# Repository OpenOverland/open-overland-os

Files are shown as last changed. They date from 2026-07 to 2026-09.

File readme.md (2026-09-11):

# ESP32-based control board

Custom designed control board build around ESP32-S3 module.

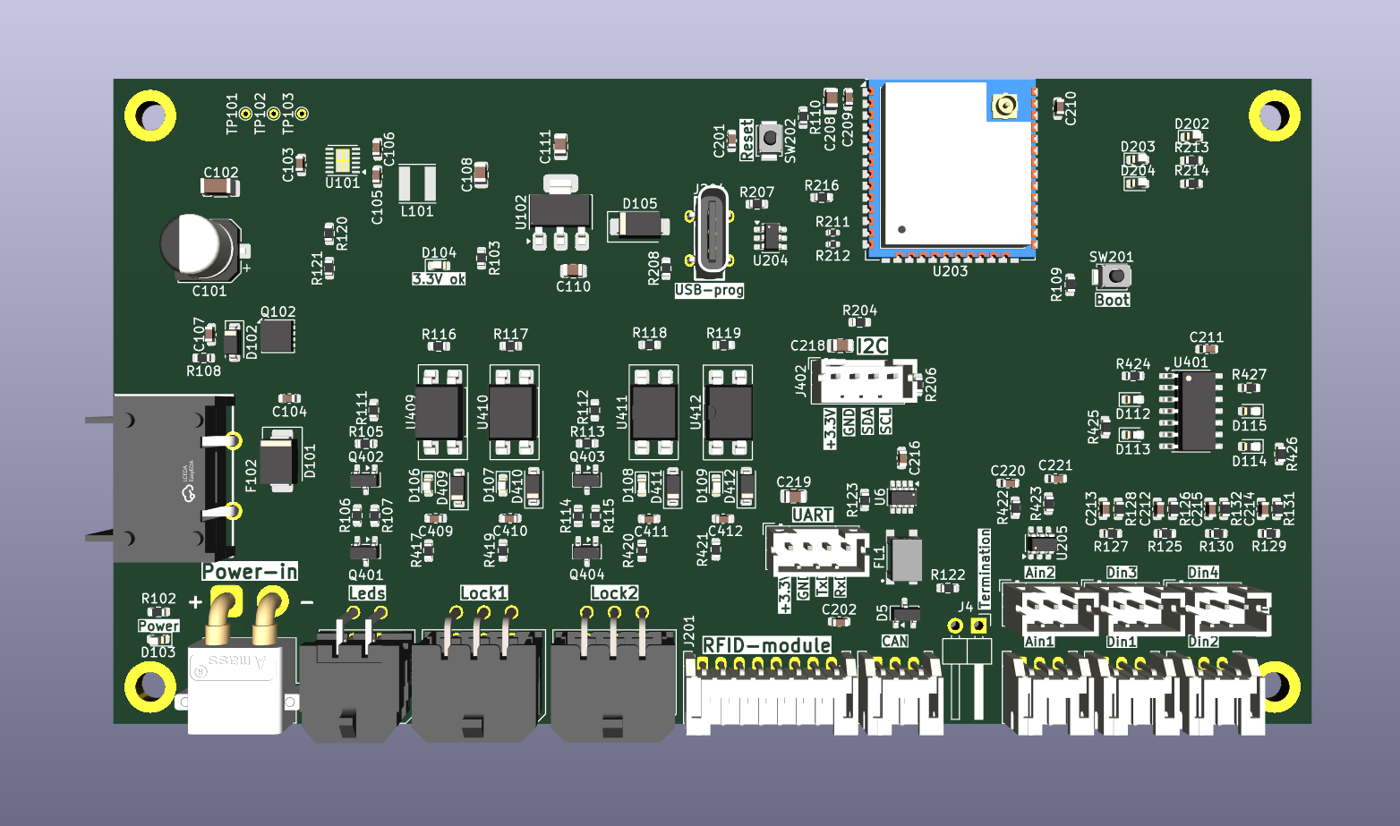
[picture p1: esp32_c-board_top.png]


### Specification:

1. Board dimensions: 130 x 70 mm, 4x M3-mounting holes (3.2mm inner diameter);
2. XT30 header as main Power-input (up to 15 Amps);
3. Blade-fuse holder on the board (in light-green color);
4. Designed around ESP32-S3-WROOM-1U module (external antenna needs to be attached to its I-PEX/u.FL connector);
5. 2x 6-pin Molex MicroFit 3.0 headers for a connection with the Locks;
6. 1x 4-pin Molex MicroFit 3.0 header for a connection with the 12V-RGB LED-strip;
7. A bunch of Horizontaly-oriented external JST-type connectors for digital and analog inputs, CAN, and RFID-module;
8. A few Vertically-oriented internal JST-type connectors for UART and I2C interfaces;
9. Communication with the RFID-module is over SPI (RC522 module considered by default).

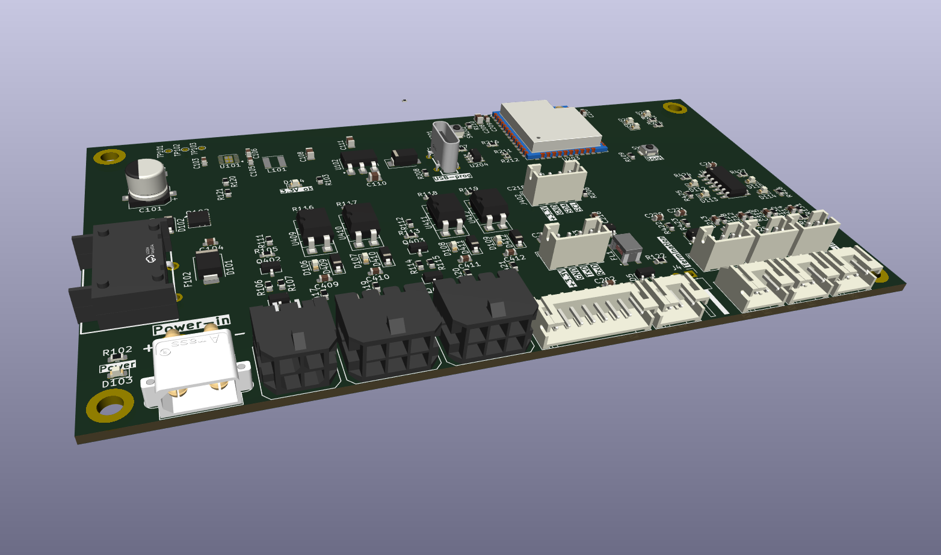
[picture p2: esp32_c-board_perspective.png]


### Main features:

- Overcurrent, overvoltage, reverse polarity protection;
- ESP32-S3 as MCU with the in-built Wi-Fi and Bluetooth capabilities;
- Controls 2x LOCKs (Southco R4-EM-9P15-150);
- 4 digital inputs (2 at board's edge), protected (optical insulation);
- 2 analog inputs (1 at board's edge), protected (ESD);
- 12V input power indication;
- CAN-bus interface with the 120-Ohm termination jumper (at board's edge);
- On-board RFID-module connector (at board's edge);
- Additional CAN-interface with the 120-Ohms termination jumper;
- Internal headers for I2C and UART interfaces;
- Battery voltage measurement circuit
- Transformed 3.3V power indication;
- Automotive-grade power supply (peak voltages resistant);
- 4-pin Molex MicroFit 3.0 connector for Addressable RGB LED-strip (WS2815 type only - 12V)

-------------

### RC522 vs. PN532

**RC522**

`Pros`

Very inexpensive (about 5$/pcs.).
Excellent for MIFARE Classic applications.
Easy to use.
Low power consumption.

`Cons`

Primarily supports ISO14443A.
No NFC functionality.
*Shorter reading distance.*
Many low-cost modules use poorly tuned antennas, reducing performance.

**PN532**

`Pros`

Full-featured NFC controller.
Supports all three NFC operating modes:
RFID/NFC Reader
Card Emulation
Peer-to-Peer
Compatible with Android smartphones.
Supports a wider variety of RFID/NFC card types.
*Generally offers better sensitivity and longer read range.*
Most breakout boards allow selecting SPI, I²C, or UART via jumpers or switches.

`Cons`

More expensive (about 8$/pcs.).
Slightly more complex to integrate.
*Higher power consumption.*

-------------

### Version history

**v2a**
This version is designed for each door (2x locks only)

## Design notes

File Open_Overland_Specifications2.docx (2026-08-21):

OPEN OVERLAND

Door Controller Module

Hardware Specification v1.3

Confidential — Open Overland OS Project

# Overview

Standalone PCB controlling 2 electric door latches via NFC fob authentication. One module per 2 doors. Mounts anywhere inside aluminum storage box. Apple HomeKit compatible via HomeSpan firmware.

# 1. Power Input

- 12V DC from vehicle battery
- XT30 connector (rated 30A)
- Onboard automotive blade fuse (10A)
- Onboard 3.3V LDO regulation for MCU and NFC
- Reverse polarity protection — AO3401 P-channel MOSFET
- TVS diode on 12V rail — SMBJ13A (load dump spike protection)

# 2. Compute Module

- ESP32-S3-WROOM-1 soldered directly on board
- WiFi 802.11 b/g/n + Bluetooth 5.0 LE included
- USB-C port for programming and OTA firmware updates
- Reset button
- Boot button (firmware flash mode)
- 1× status LED green (power / armed)
- 1× status LED red (alarm / unlocked)

# 3. NFC Reader

- 1× PN532 chip on board — I2C to ESP32-S3
- Onboard antenna DISABLED
- External antenna via U.FL connector on PCB
- U.FL to SMA coax pigtail cable — 30cm length
- External antenna: flat PCB patch antenna, 13.56MHz tuned, ~40mm × 40mm, SMA connector
- Antenna mounts behind door panel — completely invisible from outside
- Reads ISO 14443A NFC fobs and cards
- Reads through 3mm aluminum at 3–5cm range
- Antenna positioned by installer at any door panel location

# 4. Latch Outputs (2×)

- 2× Molex Microfit 3.0 female 6-pin connector — one per door latch
- Switching: 2N2222A NPN transistor per latch
- Maximum current per latch: 1A continuous
- Decoupling: 100nF capacitor per latch circuit
- 10kΩ pull-up resistors on Pin 4 (LATCH STATUS) and Pin 6 (DOOR STATUS)
- FAIL-SECURE: GPIO LOW or floating = latch LOCKED — circuit level guarantee

Connector pinout per latch port:

Pin | Signal | Description
1 | GND | Ground
2 | +12V | Always on — from vehicle battery
3 | CTRL | Switched 12V — transistor output
4 | LATCH STATUS | Digital input — 10kΩ pull-up to 3.3V
5 | NC | Not connected
6 | DOOR STATUS | Digital input — 10kΩ pull-up to 3.3V

# 5. Light Output (1×)

- Switching component: IRLZ44N N-channel MOSFET (logic level, 3.3V gate drive)
- Minimum 5A continuous at 12V — 60W capacity
- Heatsink pad on PCB under MOSFET
- Output connector: 2-pin screw terminal (12V switched + GND)
- For: 12V LED strip lighting inside aluminum storage box
- Auto-triggered by door open event (software controlled)

# 6. Tamper Input (1×)

- 1× digital input — 2-pin JST connector
- 3.3V logic level
- 10kΩ pull-up resistor on board
- Normally closed circuit
- Circuit opens = tamper event = alarm triggered in software
- For: hidden switch detecting forced box entry

# 7. I2C Expansion Port (1×)

- 4-pin JST connector: 3.3V — GND — SDA — SCL
- Plug any I2C sensor without board redesign
- Examples: light sensor (auto lights), temperature sensor, ADS1115 ADC (any analog sensor), microphone level module

# 8. Board Requirements

- Compact form factor — fits inside aluminum storage box
- 4× M3 mounting holes (3.2mm inner diameter)
- All connectors on same board edge for clean cable routing
- 2-layer PCB minimum
- Conformal coat recommended for moisture protection
- Operating temperature: -20°C to 80°C (Baja California rated)

# 9. Fail-Secure Requirement (Critical)

The following conditions must ALL result in latches LOCKED:

- Power loss → latches LOCKED
- GPIO floating → latches LOCKED
- MCU crash → latches LOCKED
- Firmware boot sequence → latches LOCKED
- Any undefined state → latches LOCKED

This is a hard circuit requirement. Transistor must be OFF by default. Must not depend on software state.

# 10. Compatible Latch

Specification | Value
Part Number | Southco R4-EM-9P15-150
Trigger Spring | Detent Pull to Open
Relock Type | Delayed
Microswitch | Door + Latch Status
Connector | Non-sealed
Mounting | 1/4-20 thread
Housing | Aluminum die cast
Voltage | 12–24V DC
Pry Resistance | 5,800N (1,304 lbs)
Electronic Release | 900N (202 lbs)
Cycle Life | 90,000 cycles

# 11. Connector Summary

Direction | Connector | Function
IN | XT30 2-pin | 12V power from vehicle battery
IN | USB-C | Programming + firmware updates
OUT | Molex Microfit 6-pin × 2 | Latch control — one per door
OUT | Screw terminal 2-pin | Light output — 5A, 12V switched
IN | JST 2-pin | Tamper switch input
I/O | JST 4-pin | I2C expansion port
RF | U.FL | External NFC antenna coax

# 12. Component BOM Summary

Component | Part | Function
Compute module | ESP32-S3-WROOM-1 | MCU — WiFi + BLE
NFC controller | PN532 | NFC reader chip
Light MOSFET | IRLZ44N | Light output 5A
Latch transistors | 2N2222A × 2 | Latch switching
Reverse polarity | AO3401 | P-MOSFET protection
Spike protection | SMBJ13A | TVS diode 12V rail
Overcurrent | 10A blade fuse | Input protection
Decoupling | 100nF × 2 | Latch circuits
Pull-ups | 10kΩ × 4 | Status pin pull-ups
Latch connectors | Molex 43025-0600 × 2 | 6-pin Microfit 3.0
Antenna port | U.FL connector | External NFC antenna
Status LEDs | Green + Red | Power + alarm
Buttons | Reset + Boot | Firmware control

# 13. Software — Not Anton's Scope

- HomeSpan library → Apple HomeKit integration
- Each latch → Lock accessory in Apple Home app
- Light output → Light accessory in Apple Home app
- Tamper input → Security sensor in Apple Home app
- I2C sensor → Temperature / Light sensor in Apple Home app
- NFC authentication → fob whitelist management
- WiFi modes → AP (hotspot) + Station (connect to network) simultaneously
- OTA firmware updates → over WiFi
- License → MIT open source
- Repository → github.com/openoverland

Open Overland OS — The open standard for truck camper builds.

Engineering-grade specs and vetted components — open source and free.

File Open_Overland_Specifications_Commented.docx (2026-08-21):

OPEN OVERLAND

Door Controller Module

Hardware Specification v1.3

Confidential — Open Overland OS Project

# Overview

Standalone PCB controlling 2 electric door latches via NFC fob authentication. One module per 2 doors. Mounts anywhere inside aluminum storage box. Keep in mind that it could block Wi-fi/Bluetooth signal

Apple HomeKit compatible via HomeSpan firmware. ESP32 allows HomeSpan firmware, but its development is not included in this job.

# 1. Power Input

- 12V DC from vehicle battery
- XT30 connector (rated 30A) - I could do that, but previously I suggested to use the same Molex MicroFit 3.0 (there is no reason for high currents like 15 Amps for such a small board)
- Onboard automotive blade fuse (10A) - Blade Fuse acceptable, but I’d suggest to use 2-5A
- Onboard 3.3V LDO regulation for MCU and NFC
- Reverse polarity protection — AO3401 P-channel MOSFET
- TVS diode on 12V rail — SMBJ13A (load dump spike protection)

# 2. Compute Module

- ESP32-S3-WROOM-1 soldered directly on board
- WiFi 802.11 b/g/n + Bluetooth 5.0 LE included
- USB-C port for programming and OTA firmware updates - OTA firmware updates depends on initial firmware developed
- Reset button
- Boot button (firmware flash mode) – not really necessary since USB used for programming
- 1× status LED green (power / armed)
- 1× status LED red (alarm / unlocked)

# 3. NFC Reader

- 1× PN532 chip on board — I2C to ESP32-S3
- Onboard antenna DISABLED
- External antenna via U.FL connector on PCB – this is kind of unusual connector for NFC (13.56Mhz vs. 2.4GHz) which could malfunctioning: the best solution is to get off-the-shelf NFC-module or to place PN532 chip very close to the antenna (i.e. on a separate board apart from ESP32). Otherwise you should go for coaxial cables and I should offer track-tuning to fit 50 Ohm Z0 impedance with the further debugging.
- U.FL to SMA coax pigtail cable — 30cm length – not sure that it is good idea, These connectors designed for 2.4GHz
- External antenna: flat PCB patch antenna, 13.56MHz tuned, ~40mm × 40mm, SMA connector – I’d recommend to place PN532 chip on that board. Communication between this board and main board around ESP32 will be much easier with the regular 4 wires (I2C-interface + power).
- Antenna mounts behind door panel — completely invisible from outside
- Reads ISO 14443A NFC fobs and cards
- Reads through 3mm aluminum at 3–5cm range – It will not work! NFC signal could not pass Aluminium
- Antenna positioned by installer at any door panel location

# 4. Latch Outputs (2×)

- 2× Molex Microfit 3.0 female 6-pin connector — one per door latch
- Switching: 2N2222A NPN transistor per latch – Possible, but I’d recommend High-side switch by P-MOSFET
- Maximum current per latch: 1A continuous
- Decoupling: 100nF capacitor per latch circuit – 1 or even 10 uF is better
- 10kΩ pull-up resistors on Pin 4 (LATCH STATUS) and Pin 6 (DOOR STATUS)
- FAIL-SECURE: GPIO LOW or floating = latch LOCKED — circuit level guarantee

Connector pinout per latch port:

Pin | Signal | Description
1 | GND | Ground
2 | +12V | Always on — from vehicle battery
3 | CTRL | Switched 12V — transistor output
4 | LATCH STATUS | Digital input — 10kΩ pull-up to 3.3V
5 | NC | Not connected
6 | DOOR STATUS | Digital input — 10kΩ pull-up to 3.3V

# 5. Light Output (1×)

- Switching component: IRLZ44N N-channel MOSFET (logic level, 3.3V gate drive) - Possible, but I’d recommend High-side switch by P-MOSFET
- Minimum 5A continuous at 12V — 60W capacity
- Heatsink pad on PCB under MOSFET
- Output connector: 2-pin screw terminal (12V switched + GND) – I assume that screw terminals are not vibration-proof and rather recommend a spring-loaded clamps.
- For: 12V LED strip lighting inside aluminum storage box
- Auto-triggered by door open event (software controlled)

# 6. Tamper Input (1×)

- 1× digital input — 2-pin JST connector – OK, do you have any preferences? They are available with the pitch from 1.25 to 3.75 mm. Most popular are 2.00 and 2.50 mm.
- 3.3V logic level
- 10kΩ pull-up resistor on board
- Normally closed circuit
- Circuit opens = tamper event = alarm triggered in software
- For: hidden switch detecting forced box entry

# 7. I2C Expansion Port (1×)

- 4-pin JST connector: 3.3V — GND — SDA — SCL
- Plug any I2C sensor without board redesign
- Examples: light sensor (auto lights), temperature sensor, ADS1115 ADC (any analog sensor), microphone level module

# 8. Board Requirements

- Compact form factor — fits inside aluminum storage box
- 4× M3 mounting holes (3.2mm inner diameter)
- All connectors on same board edge for clean cable routing
- 2-layer PCB minimum
- Conformal coat recommended for moisture protection
- Operating temperature: -20°C to 80°C (Baja California rated)

# 9. Fail-Secure Requirement (Critical)

The following conditions must ALL result in latches LOCKED:

- Power loss → latches LOCKED
- GPIO floating → latches LOCKED
- MCU crash → latches LOCKED
- Firmware boot sequence → latches LOCKED
- Any undefined state → latches LOCKED

This is a hard circuit requirement. Transistor must be OFF by default. Must not depend on software state.

# 10. Compatible Latch

Specification | Value
Part Number | Southco R4-EM-9P15-150
Trigger Spring | Detent Pull to Open
Relock Type | Delayed
Microswitch | Door + Latch Status
Connector | Non-sealed
Mounting | 1/4-20 thread
Housing | Aluminum die cast
Voltage | 12–24V DC
Pry Resistance | 5,800N (1,304 lbs)
Electronic Release | 900N (202 lbs)
Cycle Life | 90,000 cycles

# 11. Connector Summary

Direction | Connector | Function
IN | XT30 2-pin I’d recommend to use Molex Microfit 2-pin | 12V power from vehicle battery
IN | USB-C | Programming + firmware updates
OUT | Molex Microfit 6-pin × 2 | Latch control — one per door
OUT | Screw terminal 2-pin – I’d recommend to use Spring-loaded clamp terminals | Light output — 5A, 12V switched
IN | JST 2-pin | Tamper switch input
I/O | JST 4-pin | I2C expansion port
RF | U.FL – I don’t recommend | External NFC antenna coax

# 12. Component BOM Summary

Component | Part | Function
Compute module | ESP32-S3-WROOM-1 | MCU — WiFi + BLE
NFC controller | PN532 | NFC reader chip
Light MOSFET | IRLZ44N | Light output 5A
Latch transistors | 2N2222A × 2 | Latch switching
Reverse polarity | AO3401 | P-MOSFET protection
Spike protection | SMBJ13A | TVS diode 12V rail
Overcurrent | 10A blade fuse | Input protection
Decoupling | 100nF × 2 | Latch circuits
Pull-ups | 10kΩ × 4 | Status pin pull-ups
Latch connectors | Molex 43025-0600 × 2 | 6-pin Microfit 3.0
Antenna port | U.FL connector | External NFC antenna
Status LEDs | Green + Red | Power + alarm
Buttons | Reset + Boot | Firmware control

# 13. Software — Not Anton's Scope

- HomeSpan library → Apple HomeKit integration
- Each latch → Lock accessory in Apple Home app
- Light output → Light accessory in Apple Home app
- Tamper input → Security sensor in Apple Home app
- I2C sensor → Temperature / Light sensor in Apple Home app
- NFC authentication → fob whitelist management
- WiFi modes → AP (hotspot) + Station (connect to network) simultaneously
- OTA firmware updates → over WiFi
- License → MIT open source
- Repository → github.com/openoverland

Open Overland OS — The open standard for truck camper builds.

Engineering-grade specs and vetted components — open source and free.

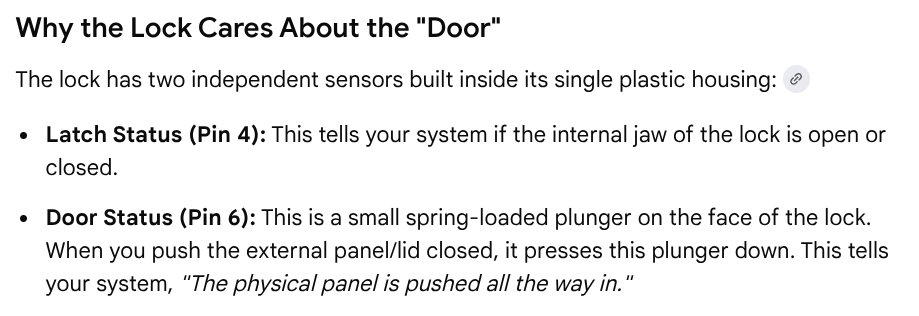
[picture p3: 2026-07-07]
HARDWARE/INFO/Screenshot from 2026-07-03 18-47-02.png

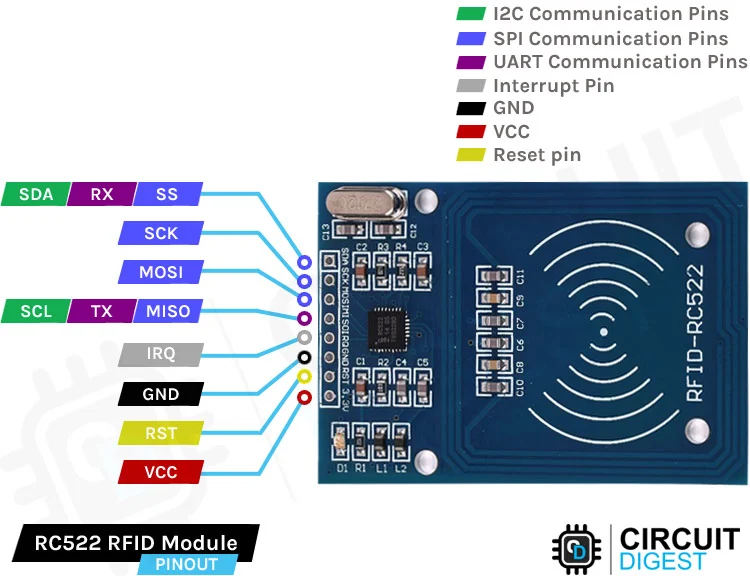
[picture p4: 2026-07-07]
HARDWARE/INFO/RC522-RFID-Reader-Module-Pinout.webp

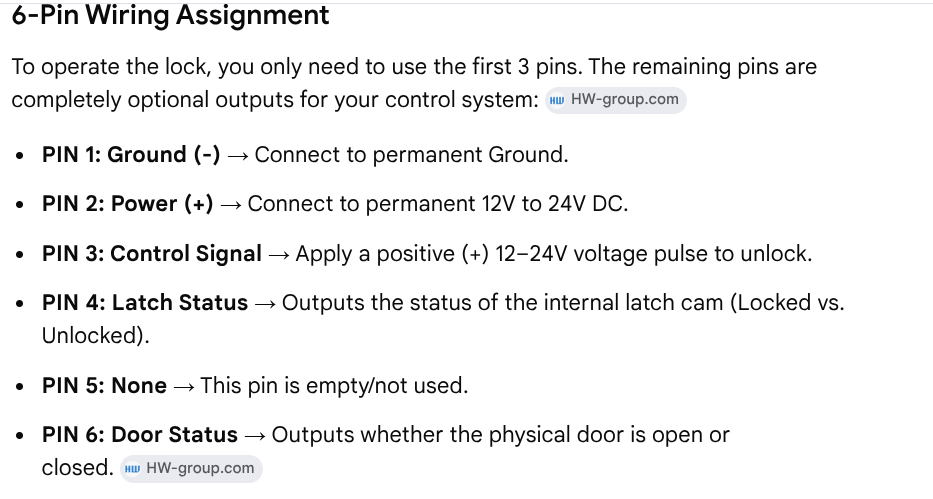
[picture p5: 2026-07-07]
HARDWARE/INFO/Screenshot from 2026-07-03 18-45-30.png

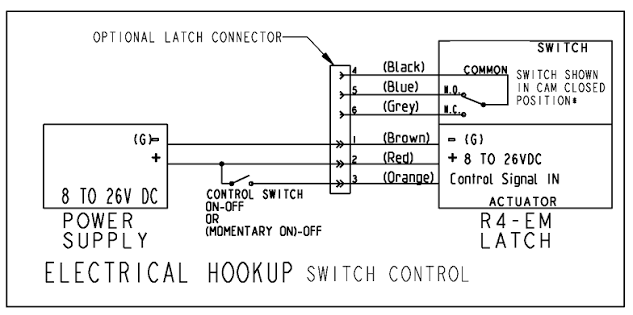
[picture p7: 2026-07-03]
HARDWARE/INFO/pinout.png

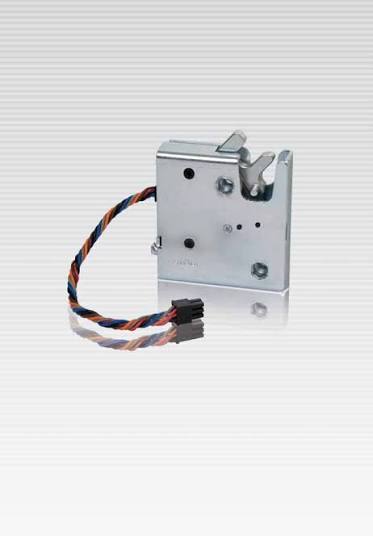
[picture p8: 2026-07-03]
lock.jpeg

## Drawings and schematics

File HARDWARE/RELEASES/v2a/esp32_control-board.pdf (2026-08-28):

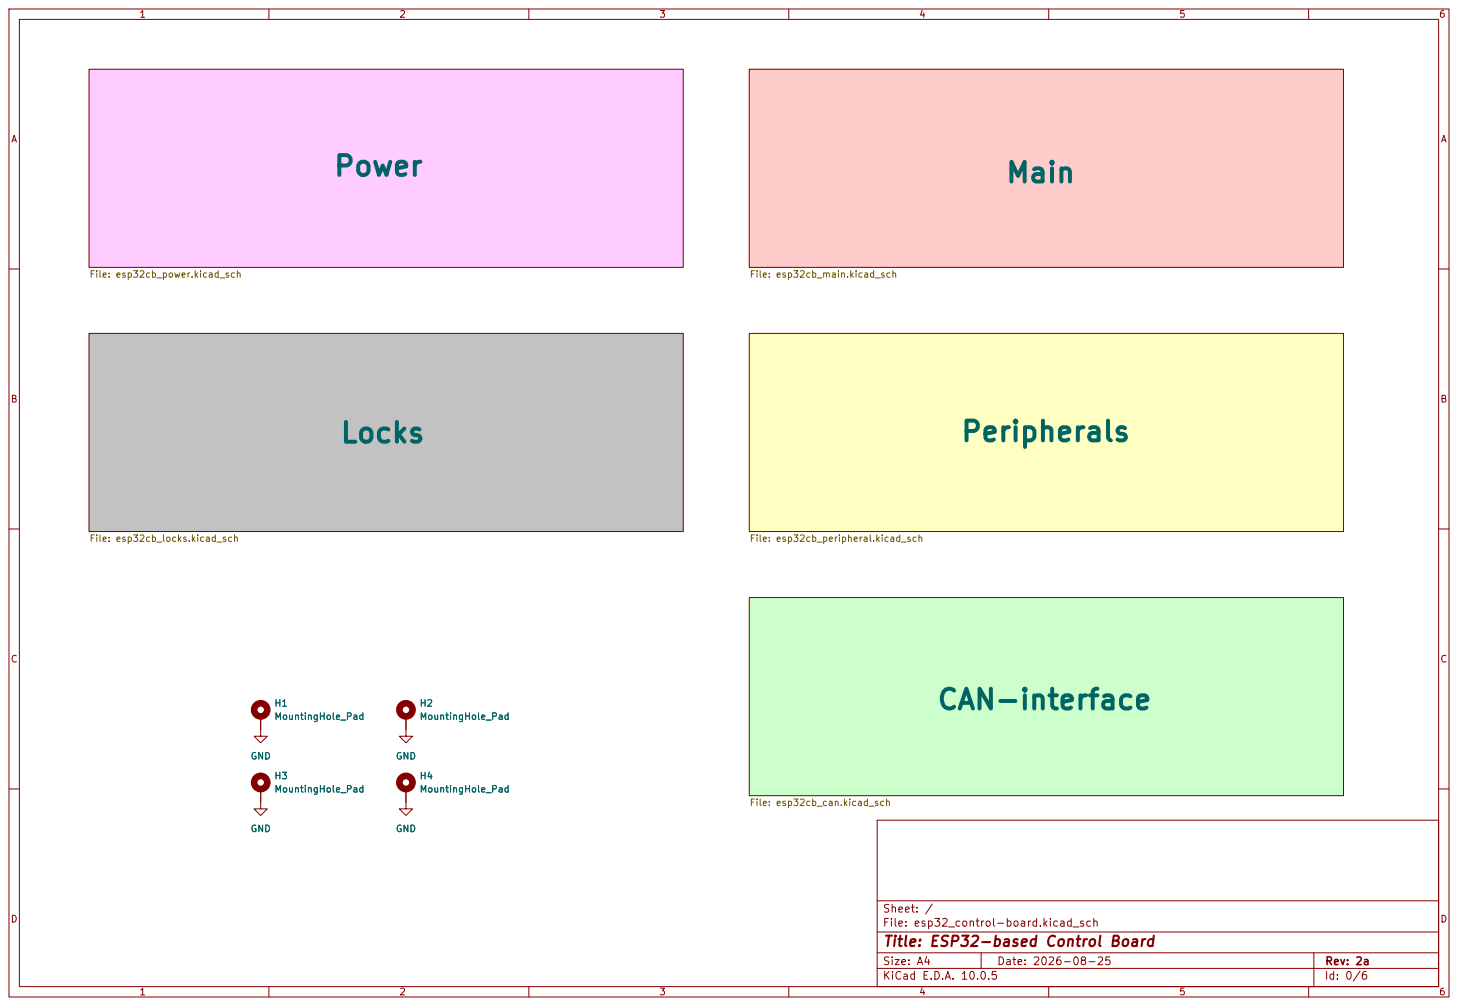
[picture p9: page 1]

Sheet: /
File: esp32_control-board.kicad_sch
Title: ESP32-based Control Board

Size: A4 | Rev: 2a
KiCad E.D.A. 10.0.5 | Id: 0/6

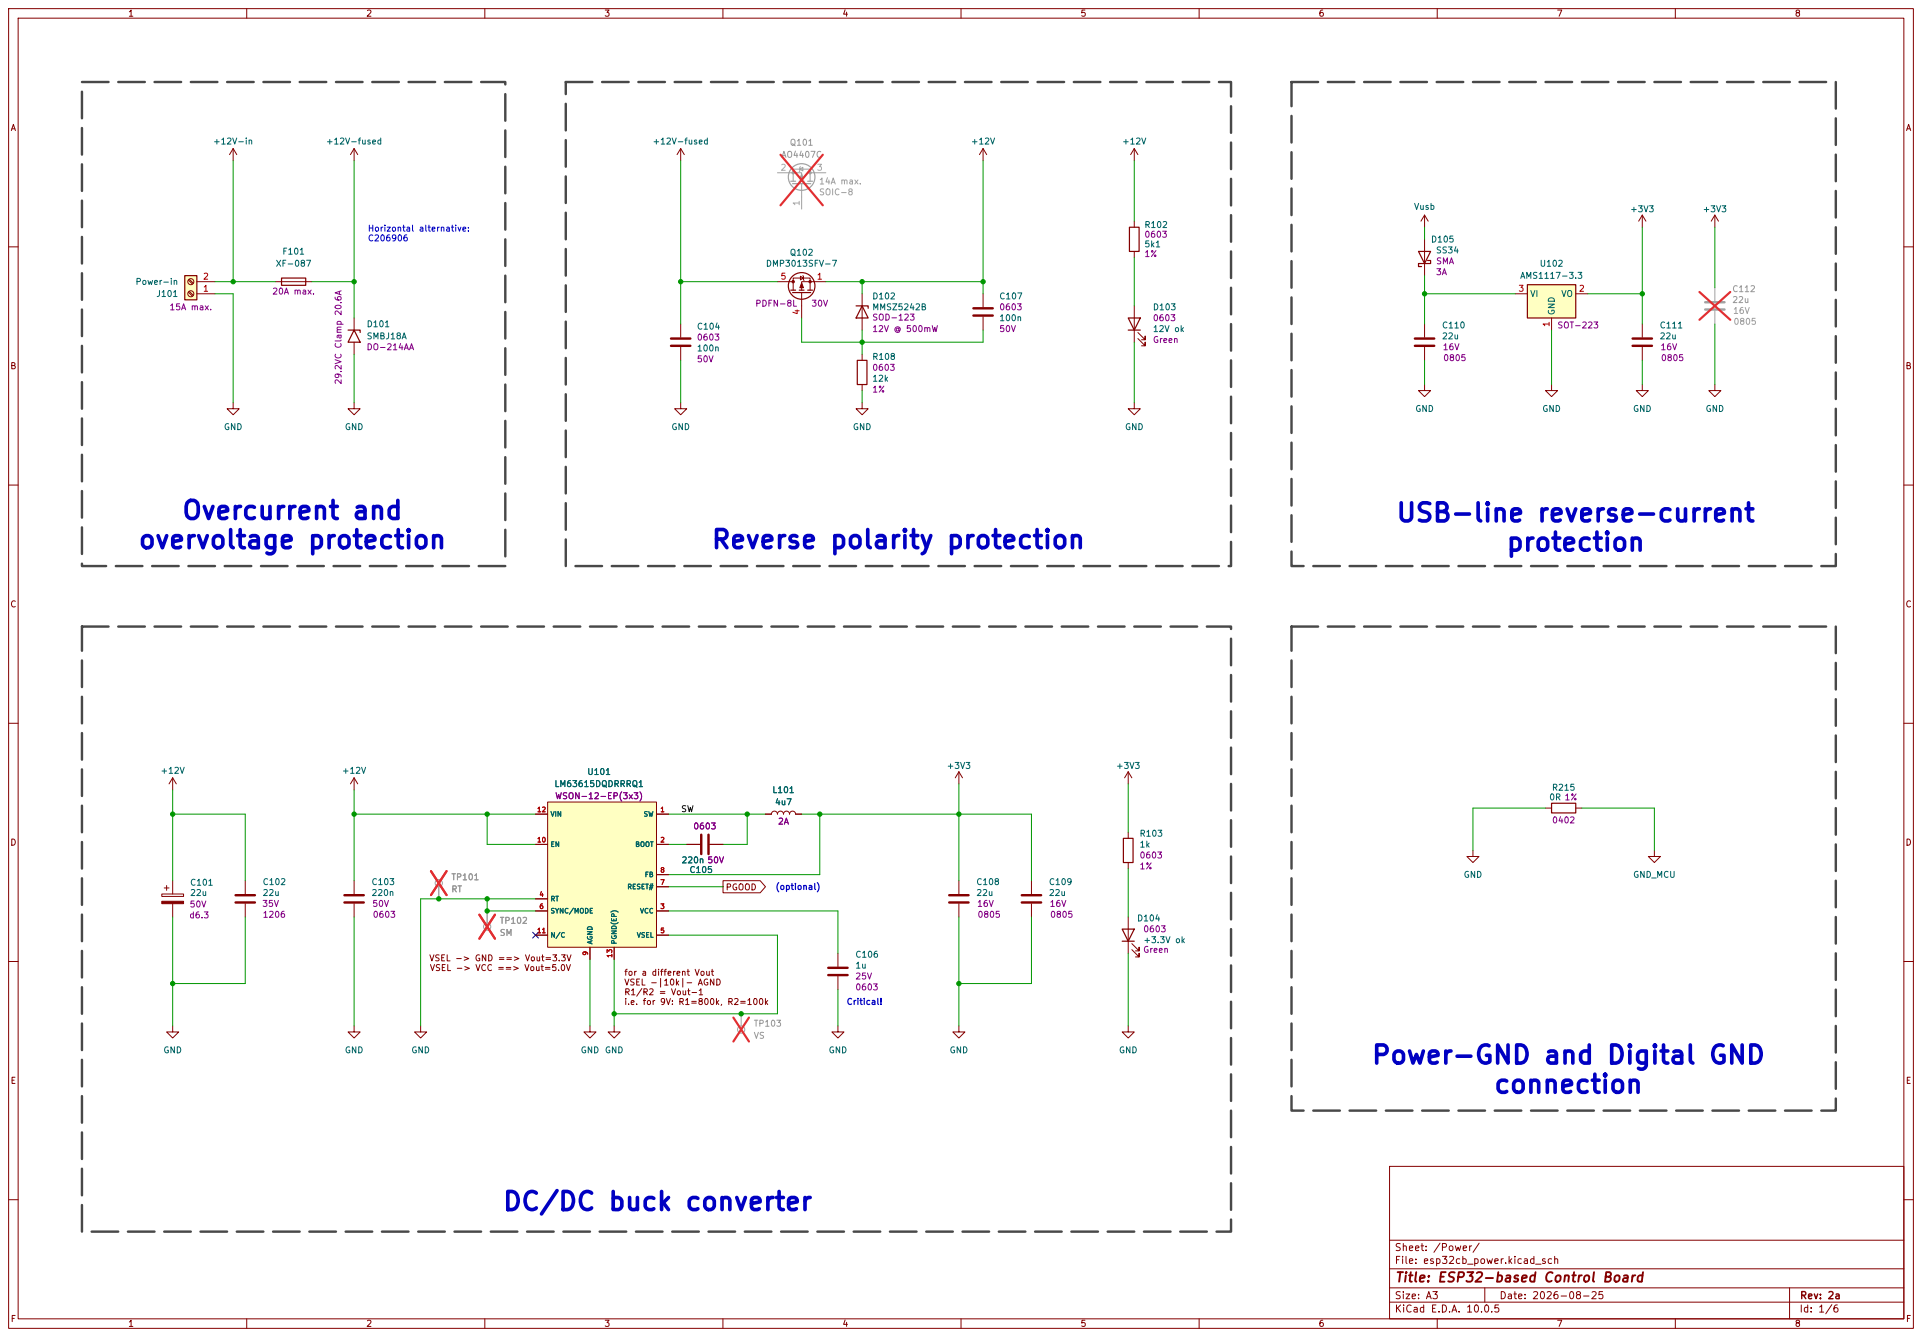
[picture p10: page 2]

SMBJ18A DO-214AA 29.2VC Clamp 20.6A GND +12V-fused

Critical! DC/DC buck converter

Power-GND and Digital GND

Sheet: /Power/
File: esp32cb_power.kicad_sch
Title: ESP32-based Control Board

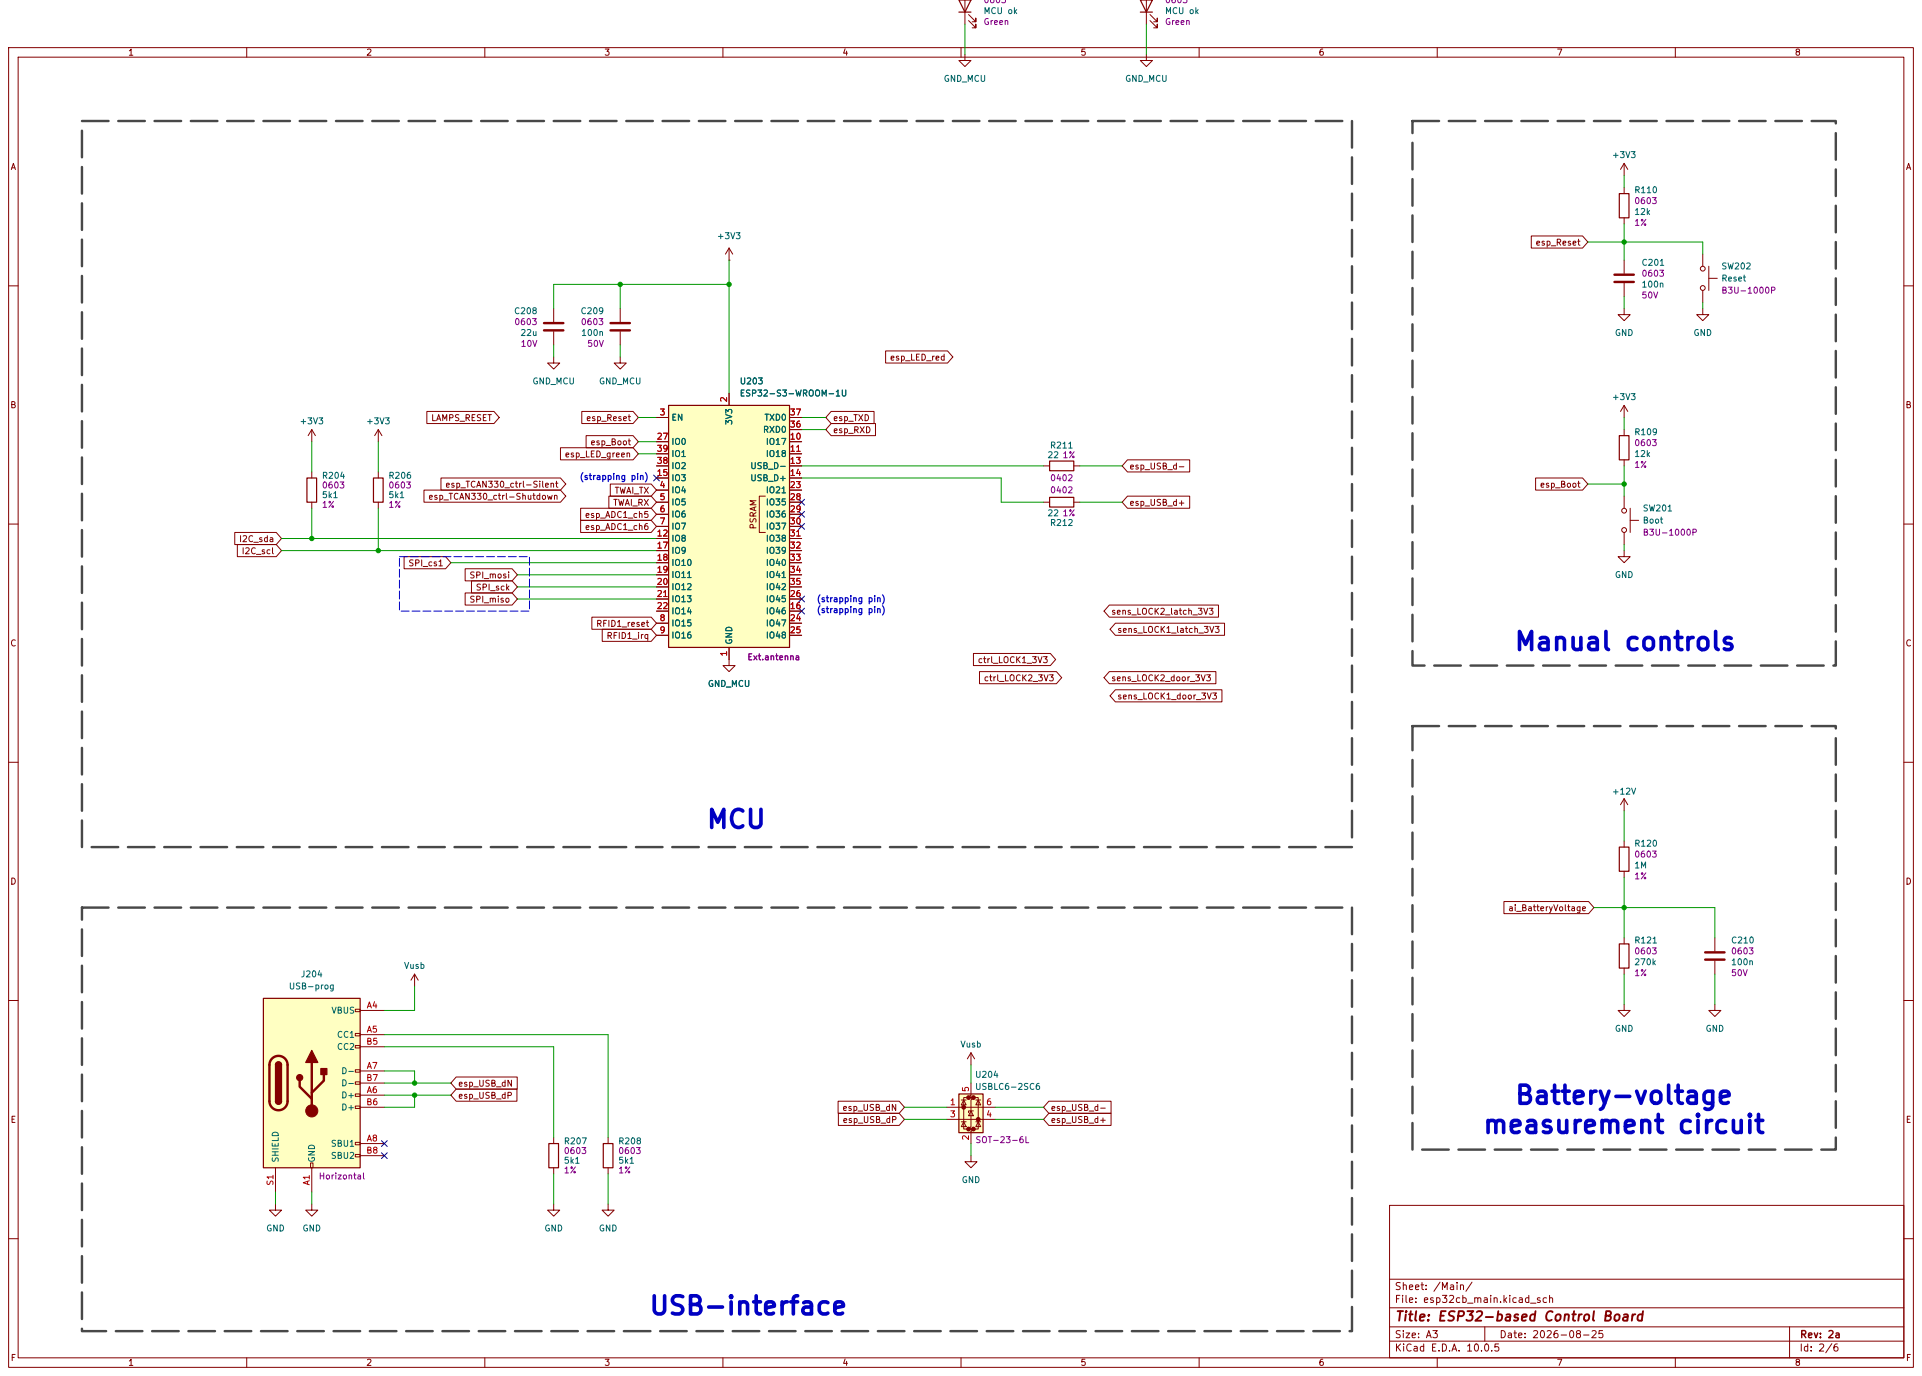
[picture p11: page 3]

D202 MCU ok 0603 Green PSRAM GND

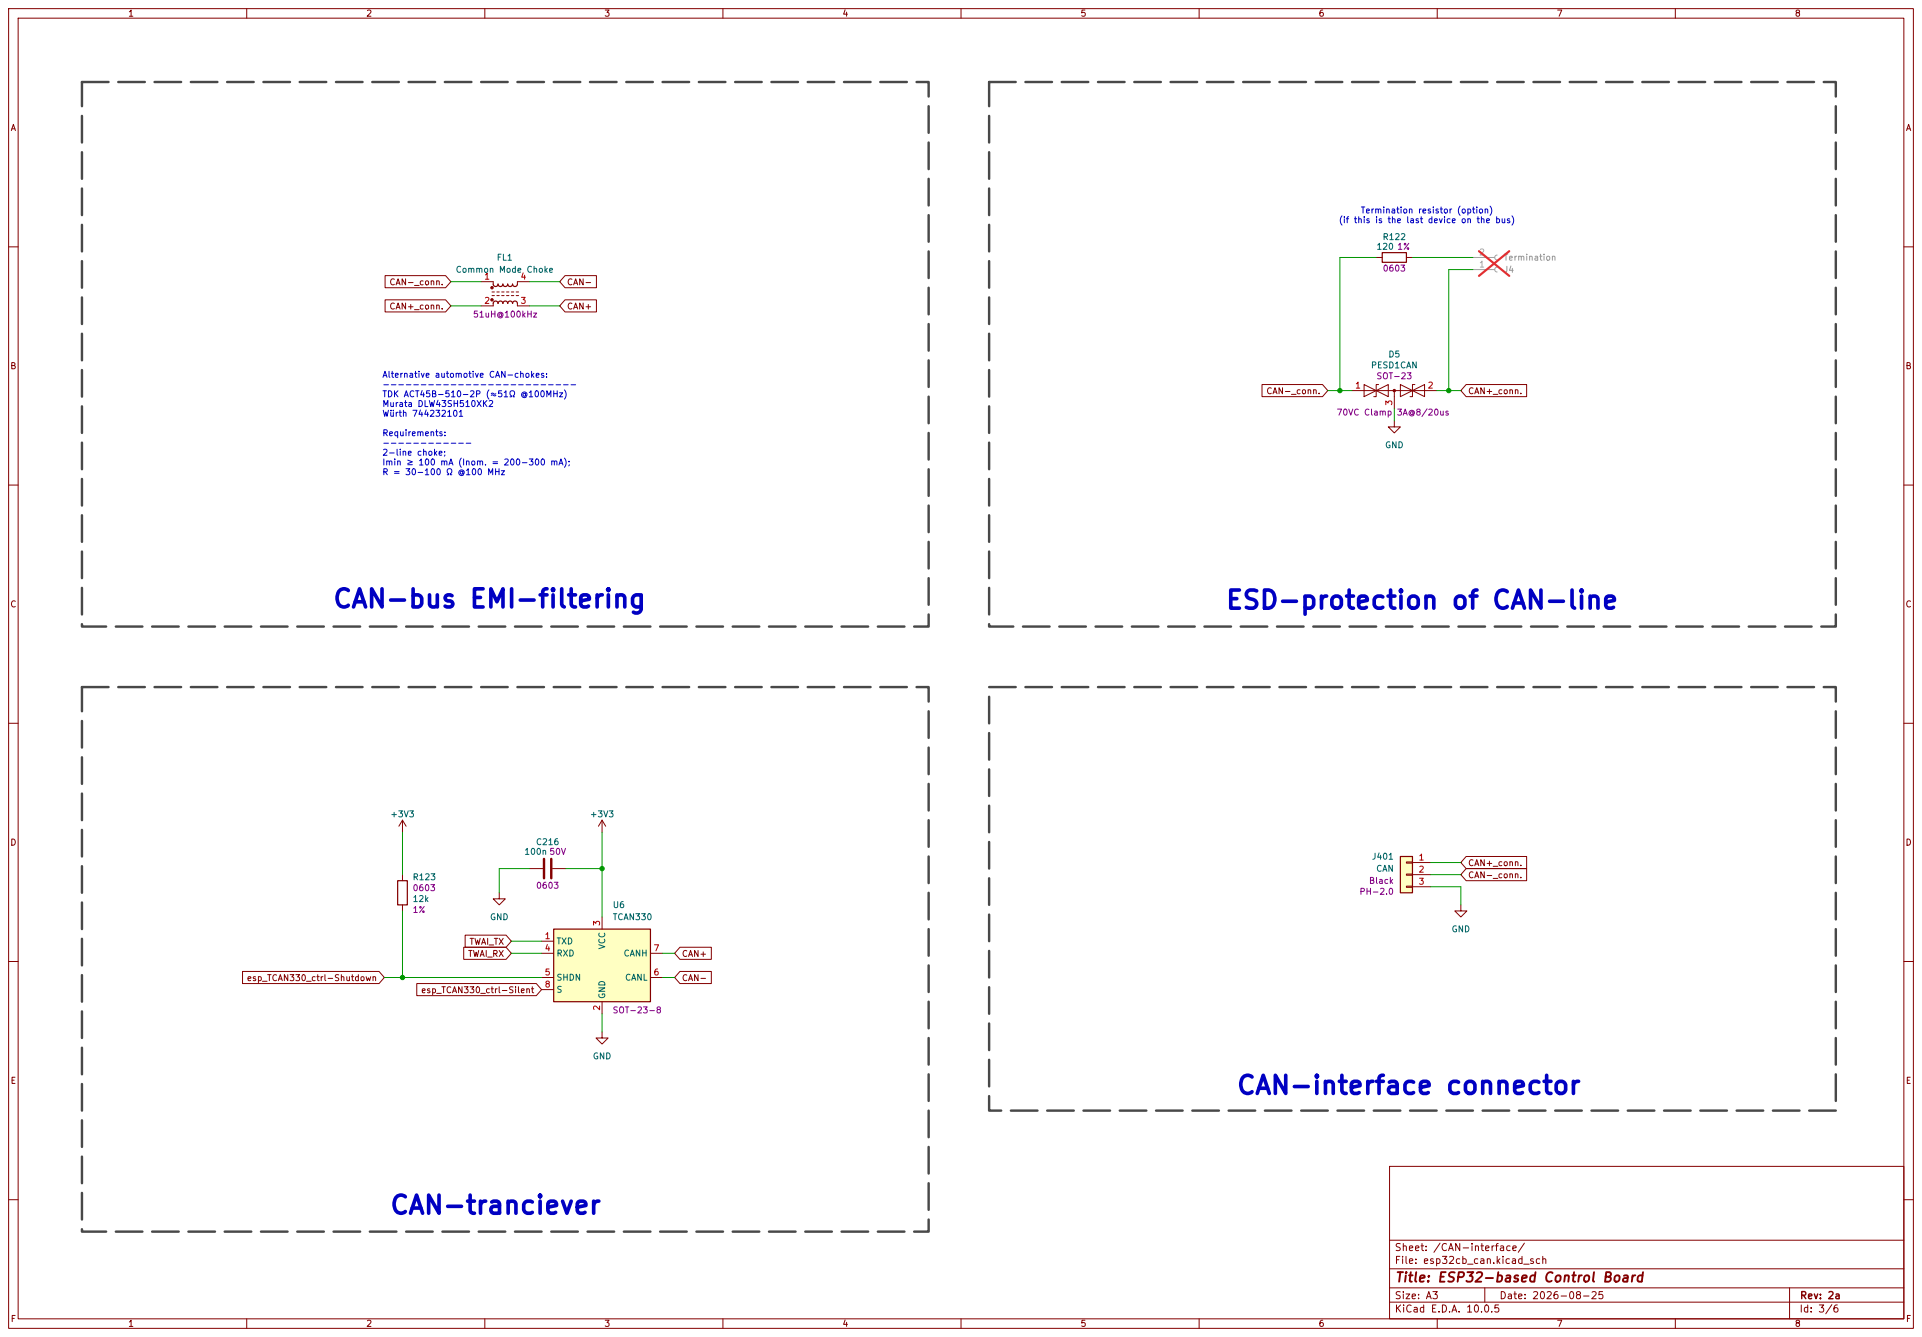
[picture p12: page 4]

Termination resistor (option)
(if this is the last device on the bus)

Alternative automotive CAN-chokes: --------------------------

TDK ACT45B-510-2P (≈51Ω @100MHz) Murata DLW43SH510XK2 Würth 744232101 Requirements: ------------

Imin ≥ 100 mА (Inom. = 200-300 mА); R = 30-100 Ω @100 MHz CAN-bus EMI-filtering

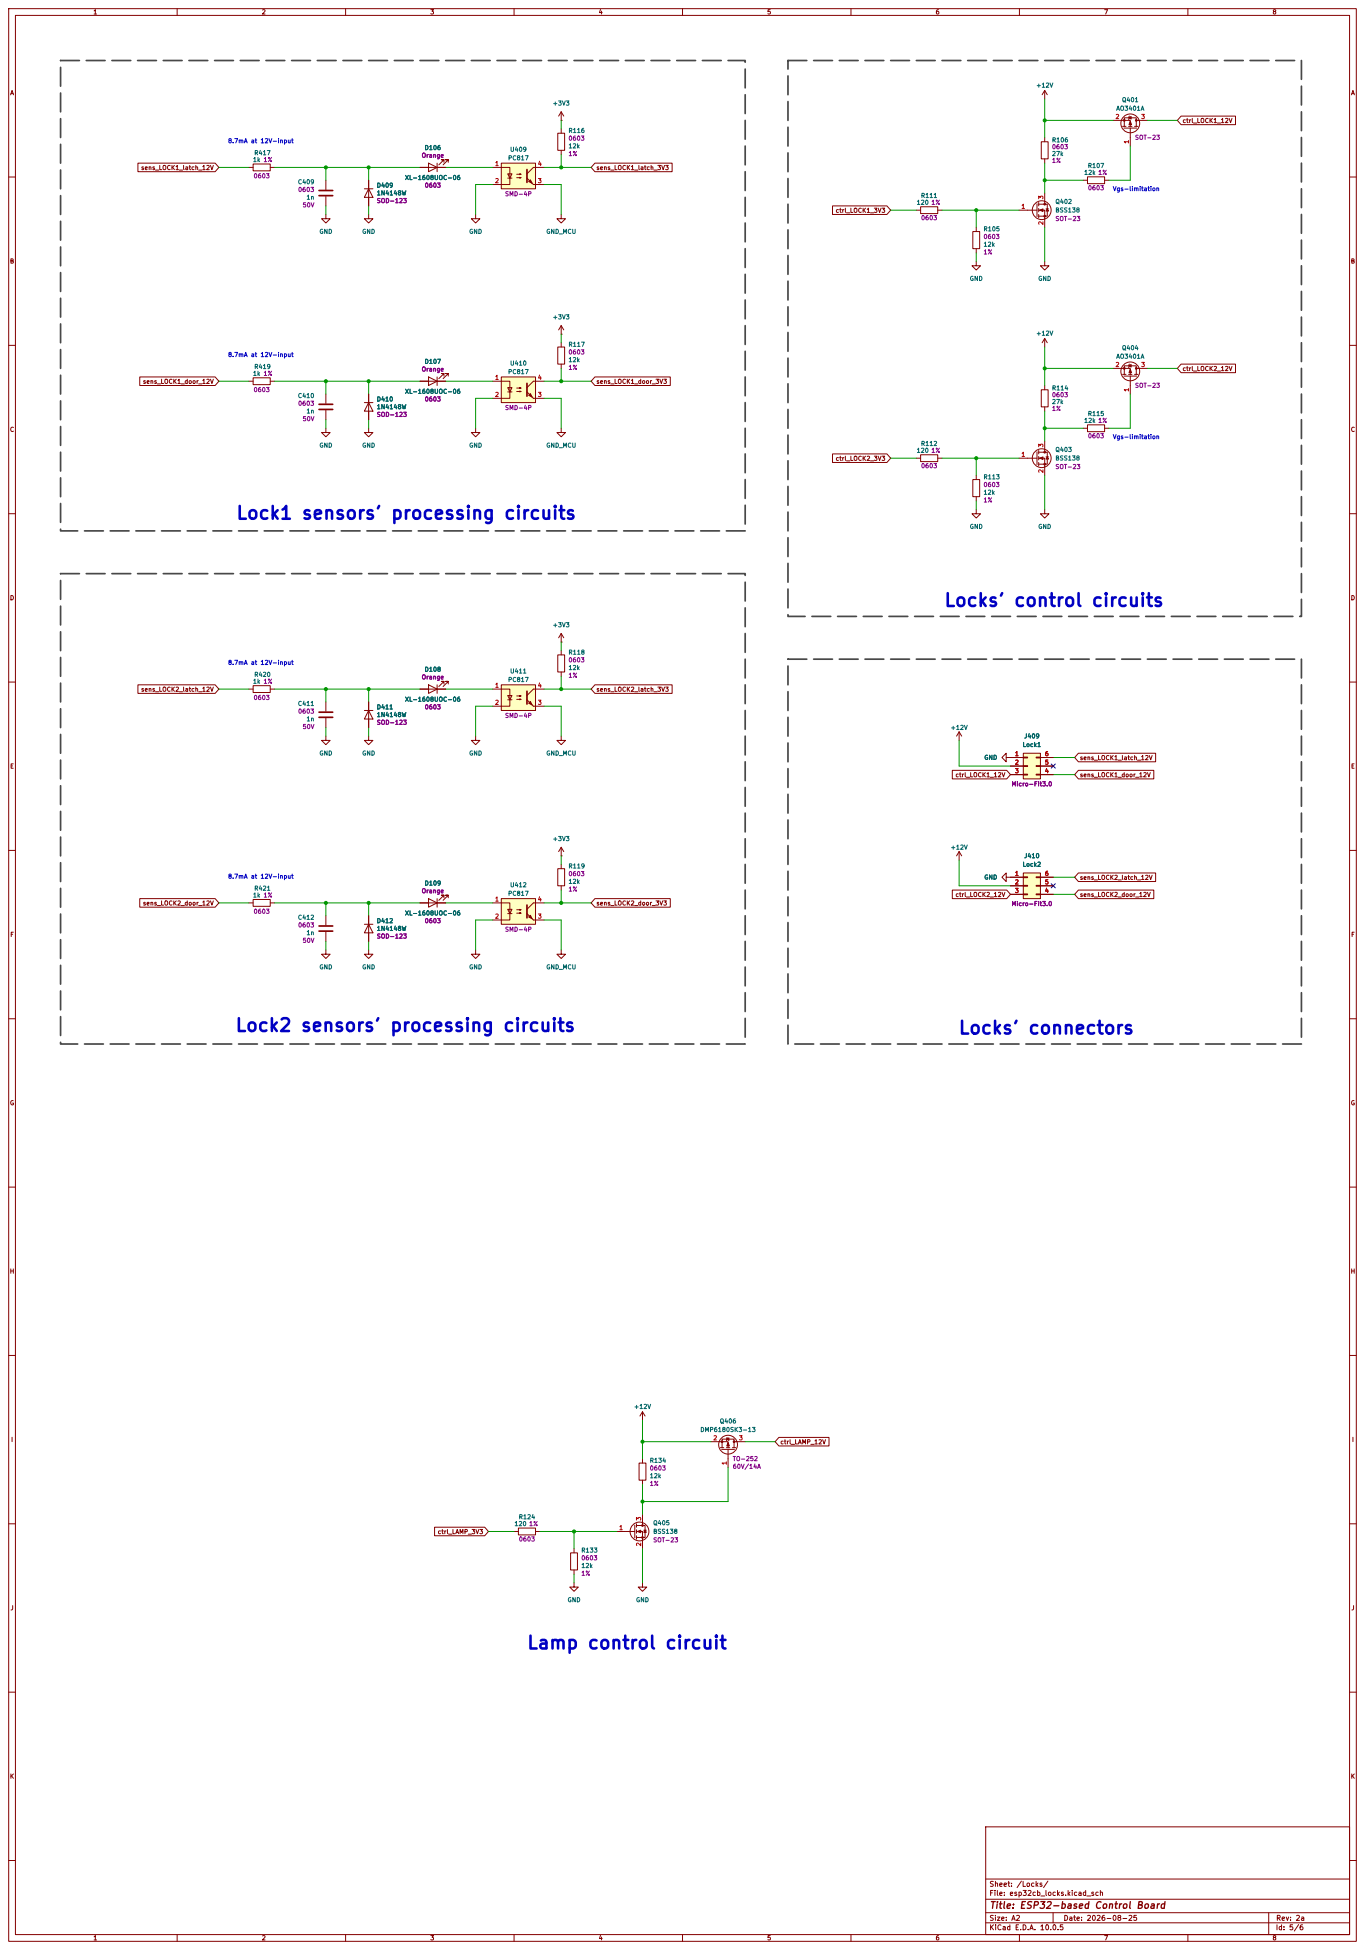
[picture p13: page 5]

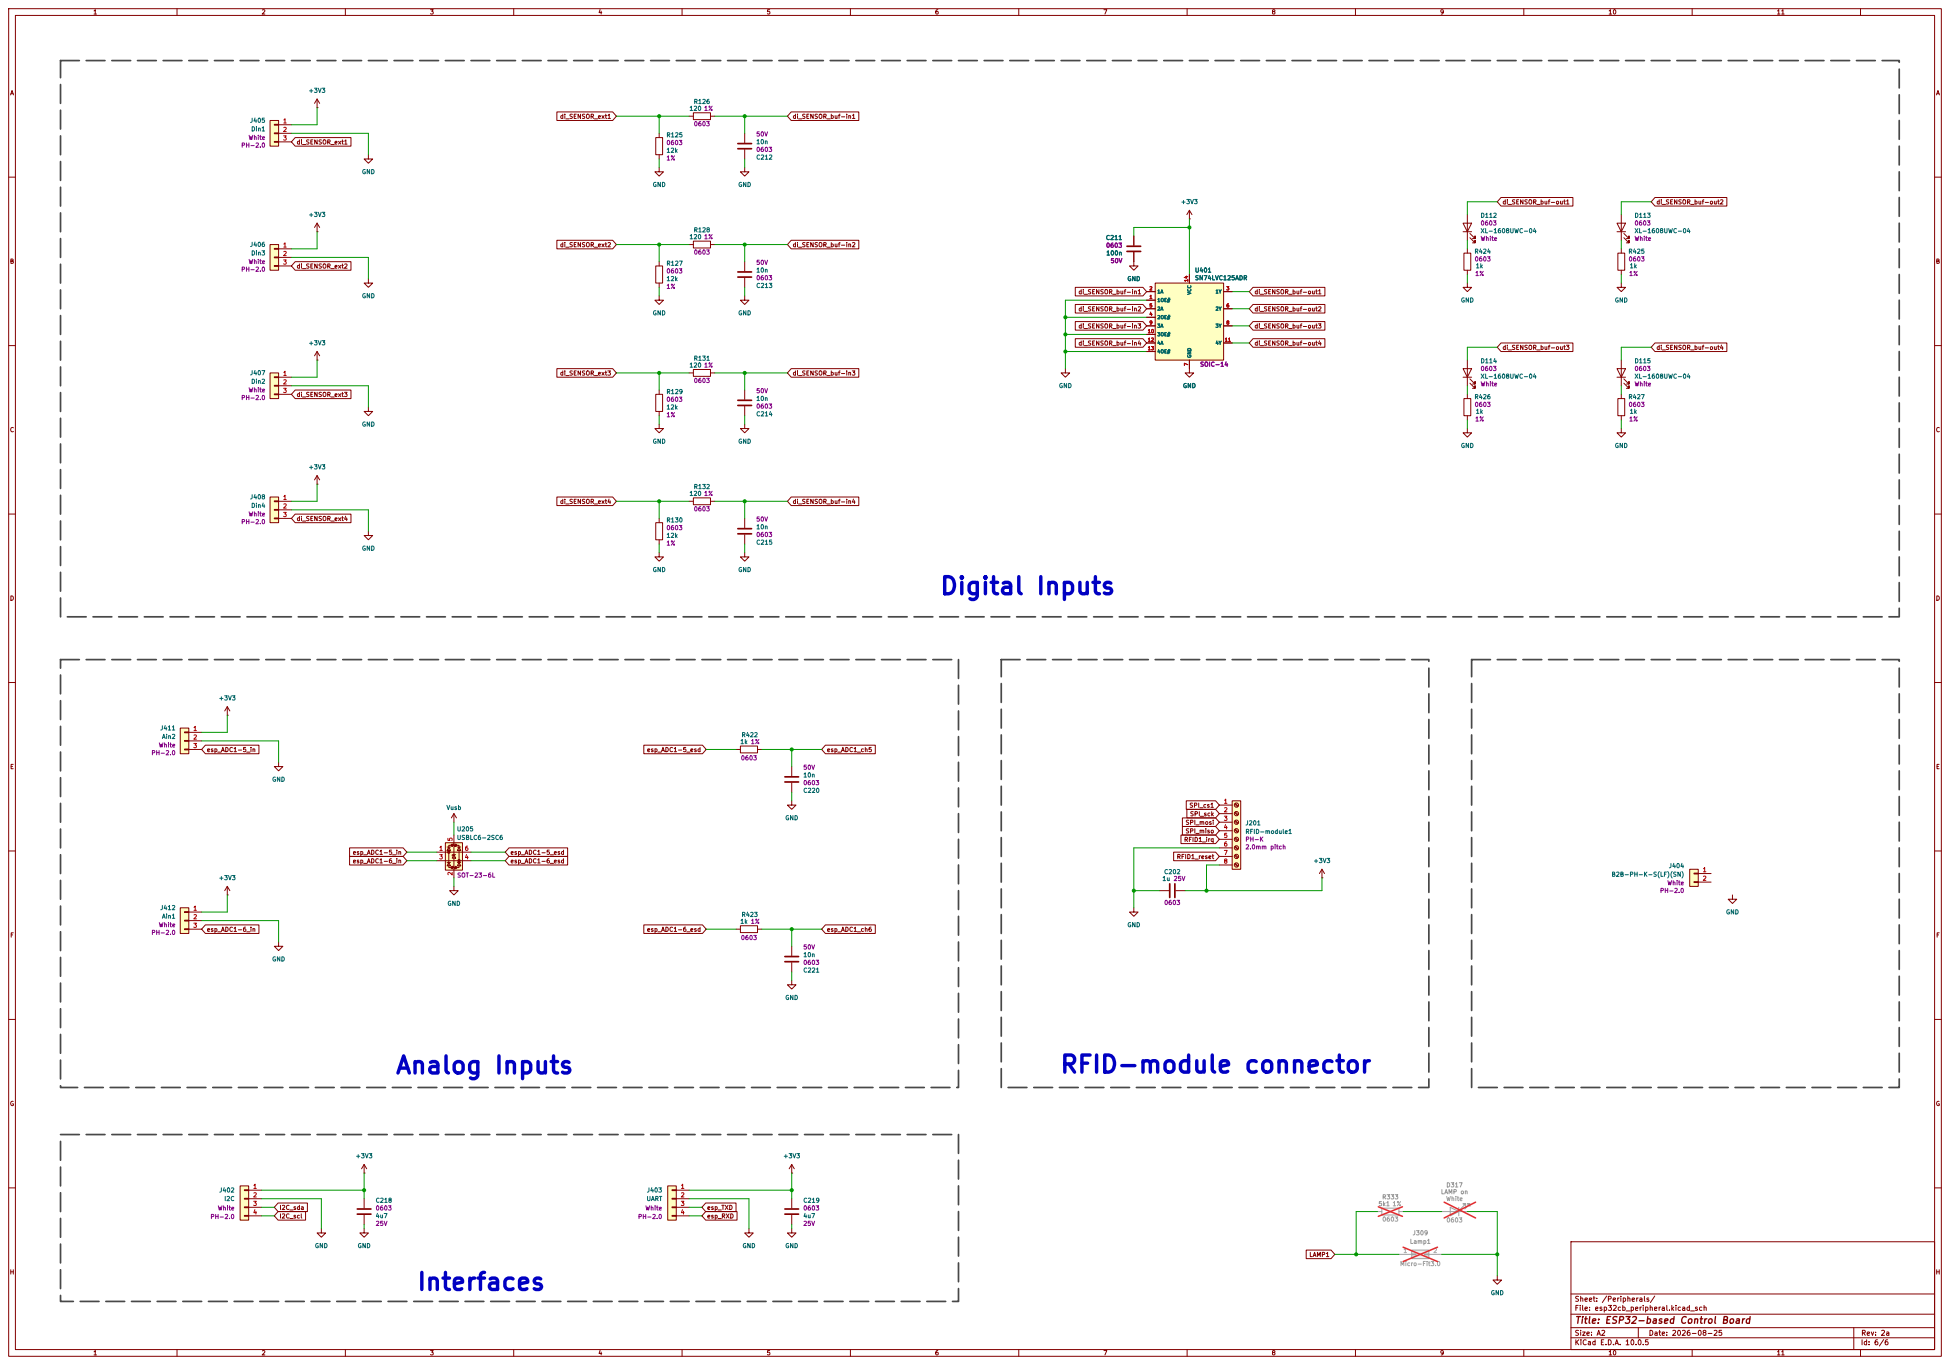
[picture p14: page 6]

J404 B2B-PH-K-S(LF)(SN) PH-2.0 White

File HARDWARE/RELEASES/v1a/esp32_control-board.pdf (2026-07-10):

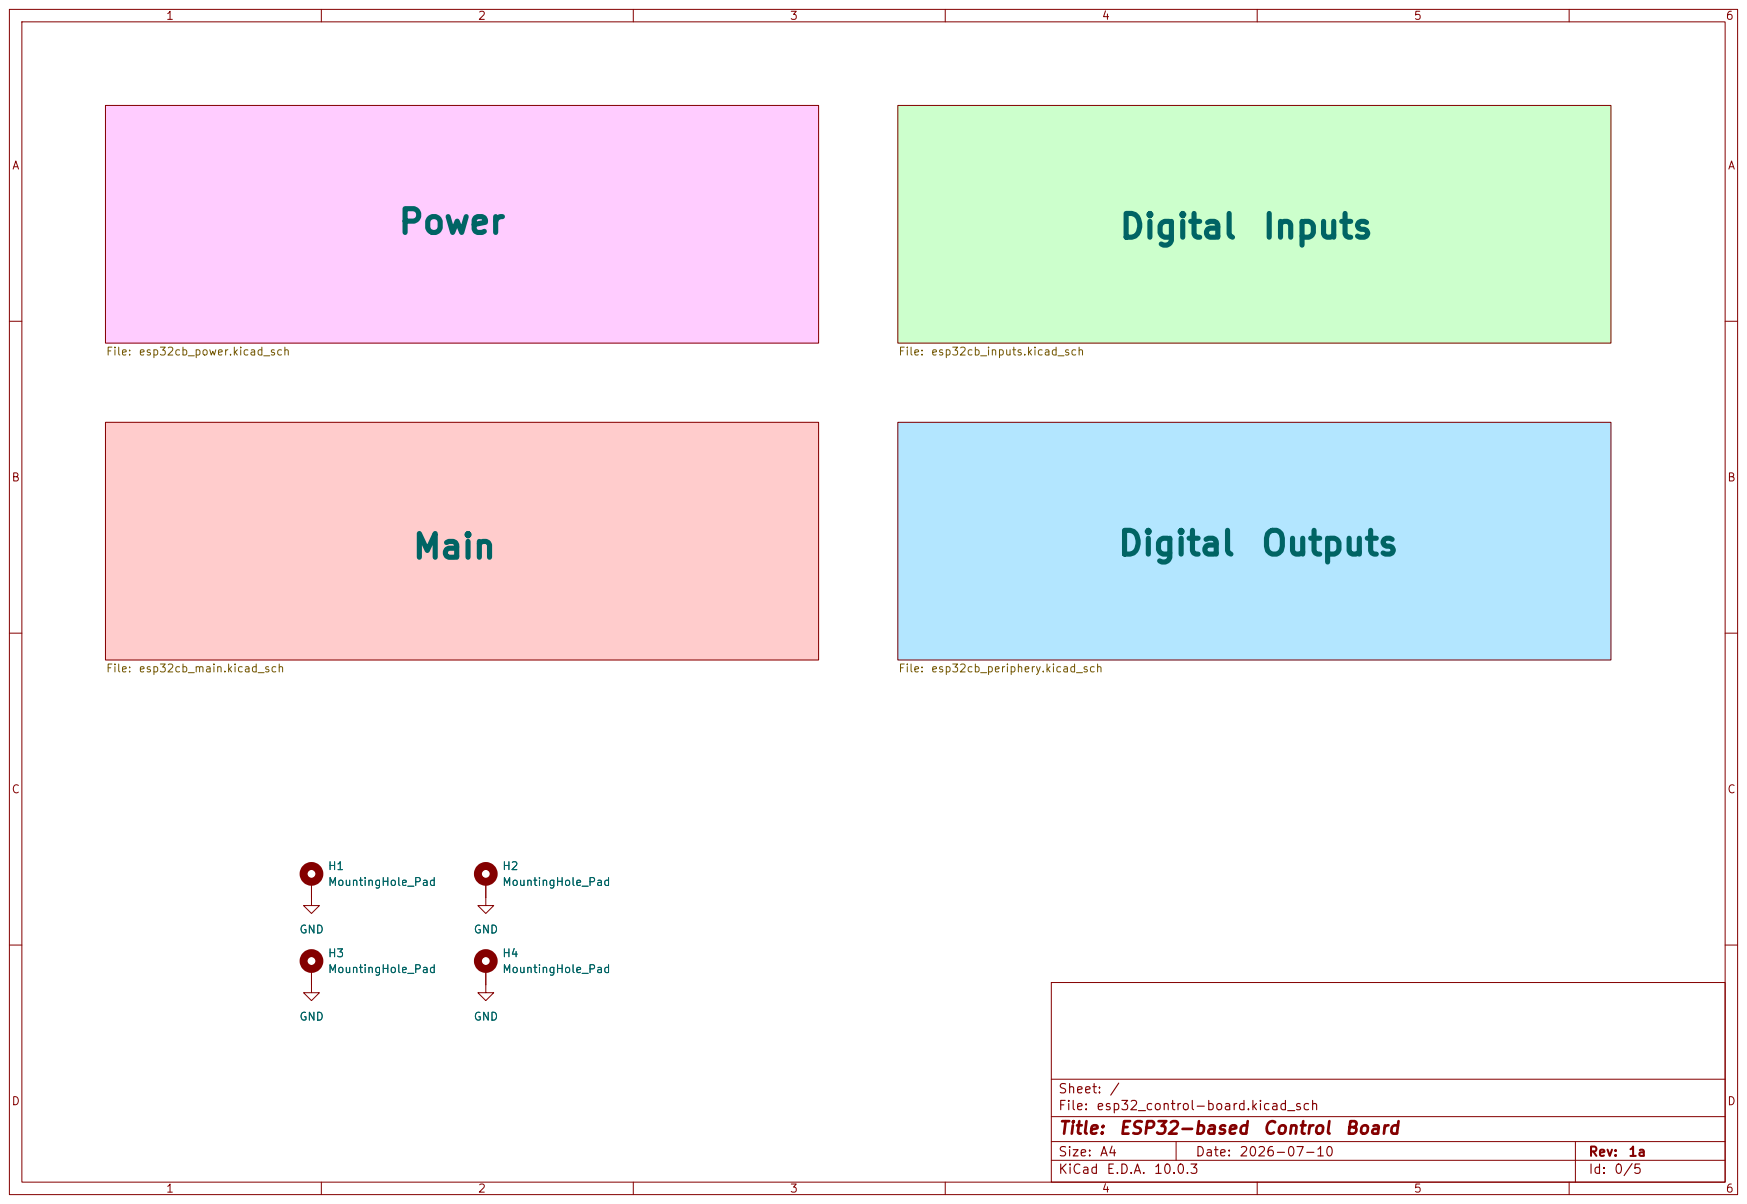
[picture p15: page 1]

Sheet: /
File: esp32_control-board.kicad_sch
Title: ESP32-based Control Board

Size: A4 | Rev: 1a
KiCad E.D.A. 10.0.3 | Id: 0/5

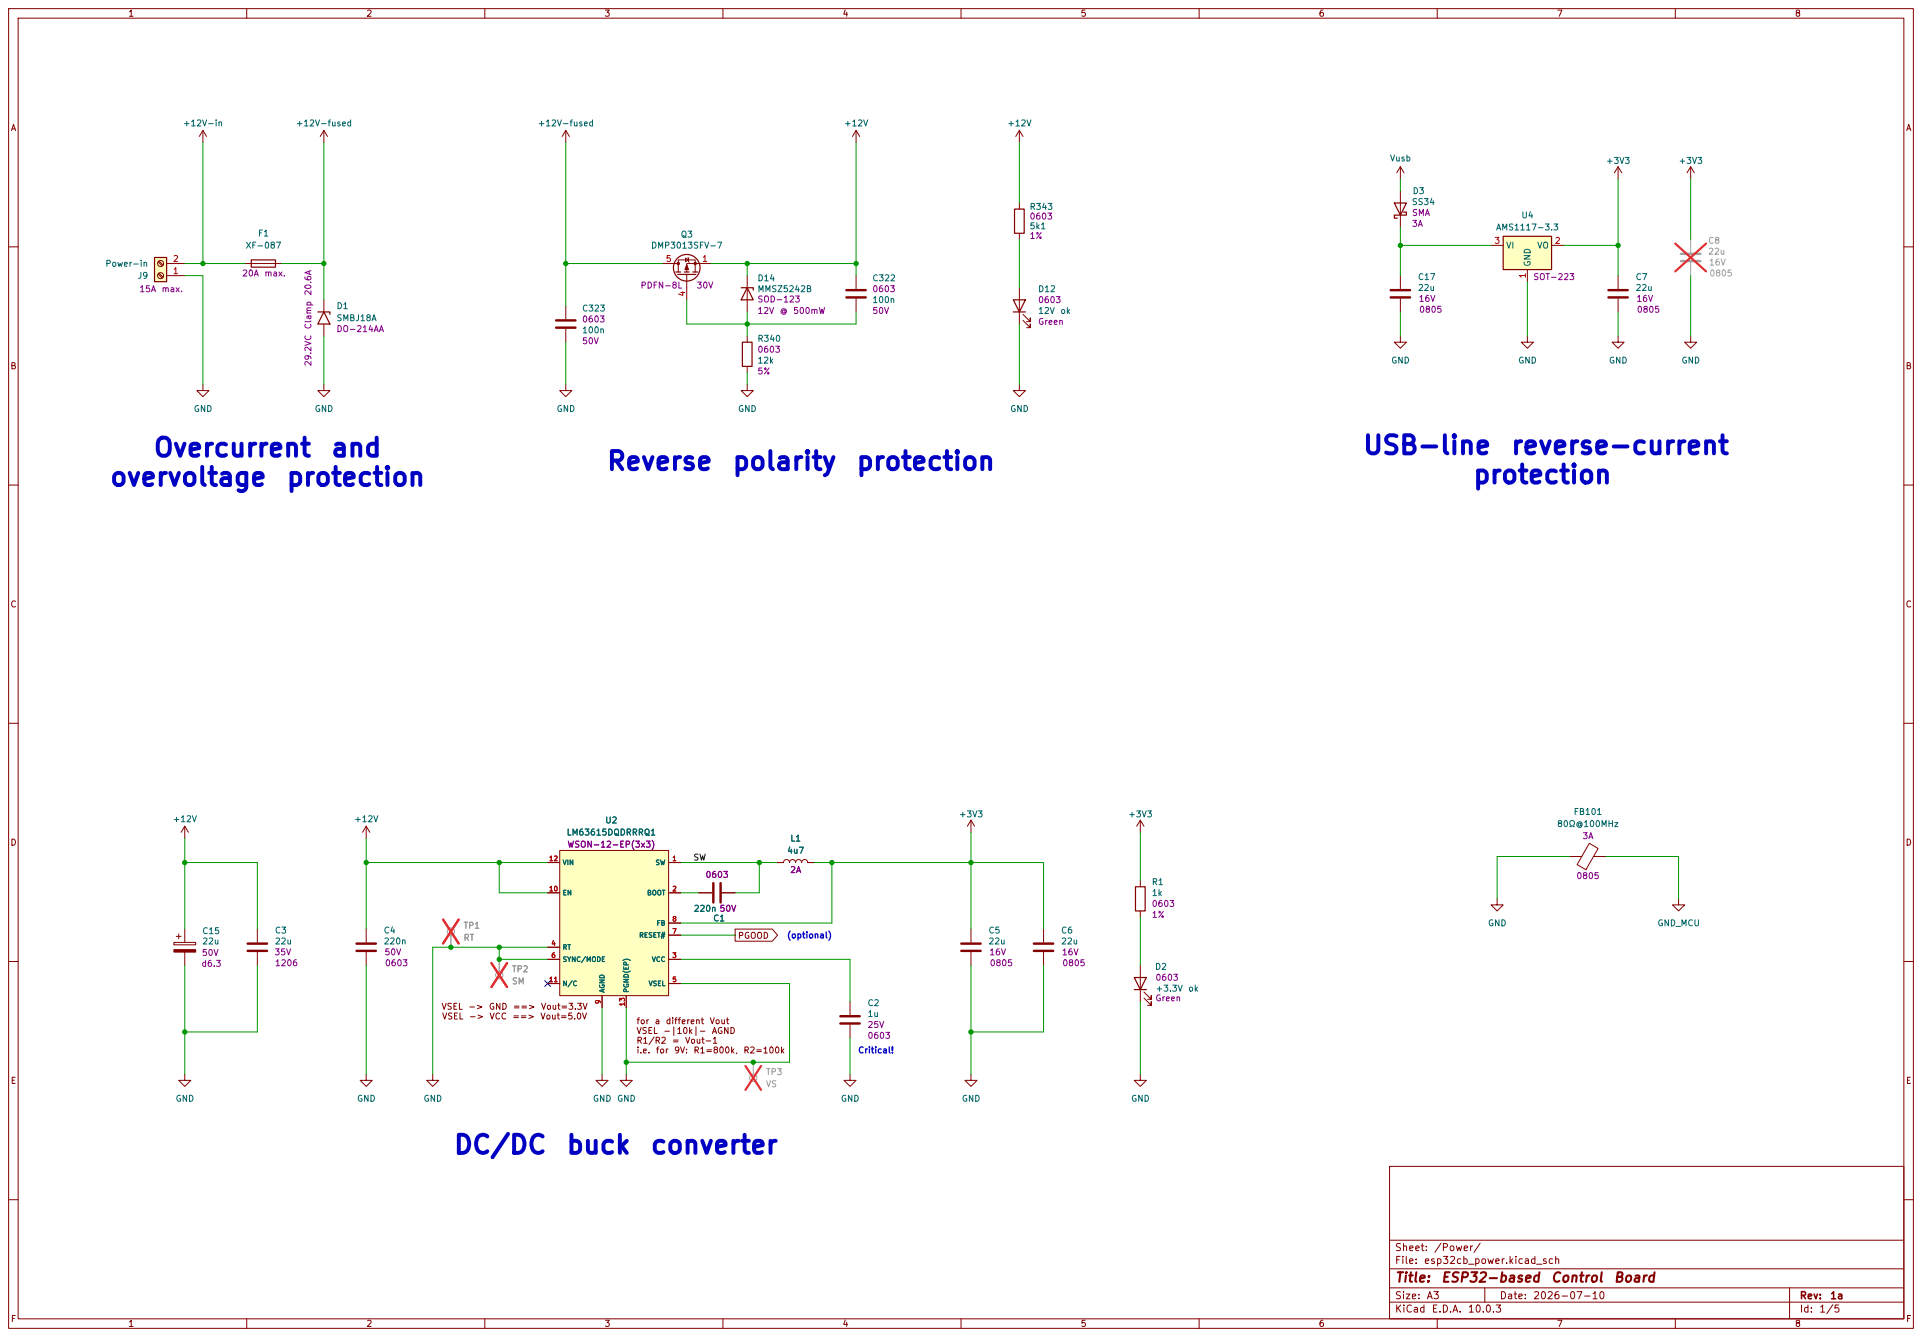
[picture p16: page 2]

DC/DC buck converter

Sheet: /Power/
File: esp32cb_power.kicad_sch
Title: ESP32-based Control Board

Size: A3 | Rev: 1a

F Date: 2026-07-10

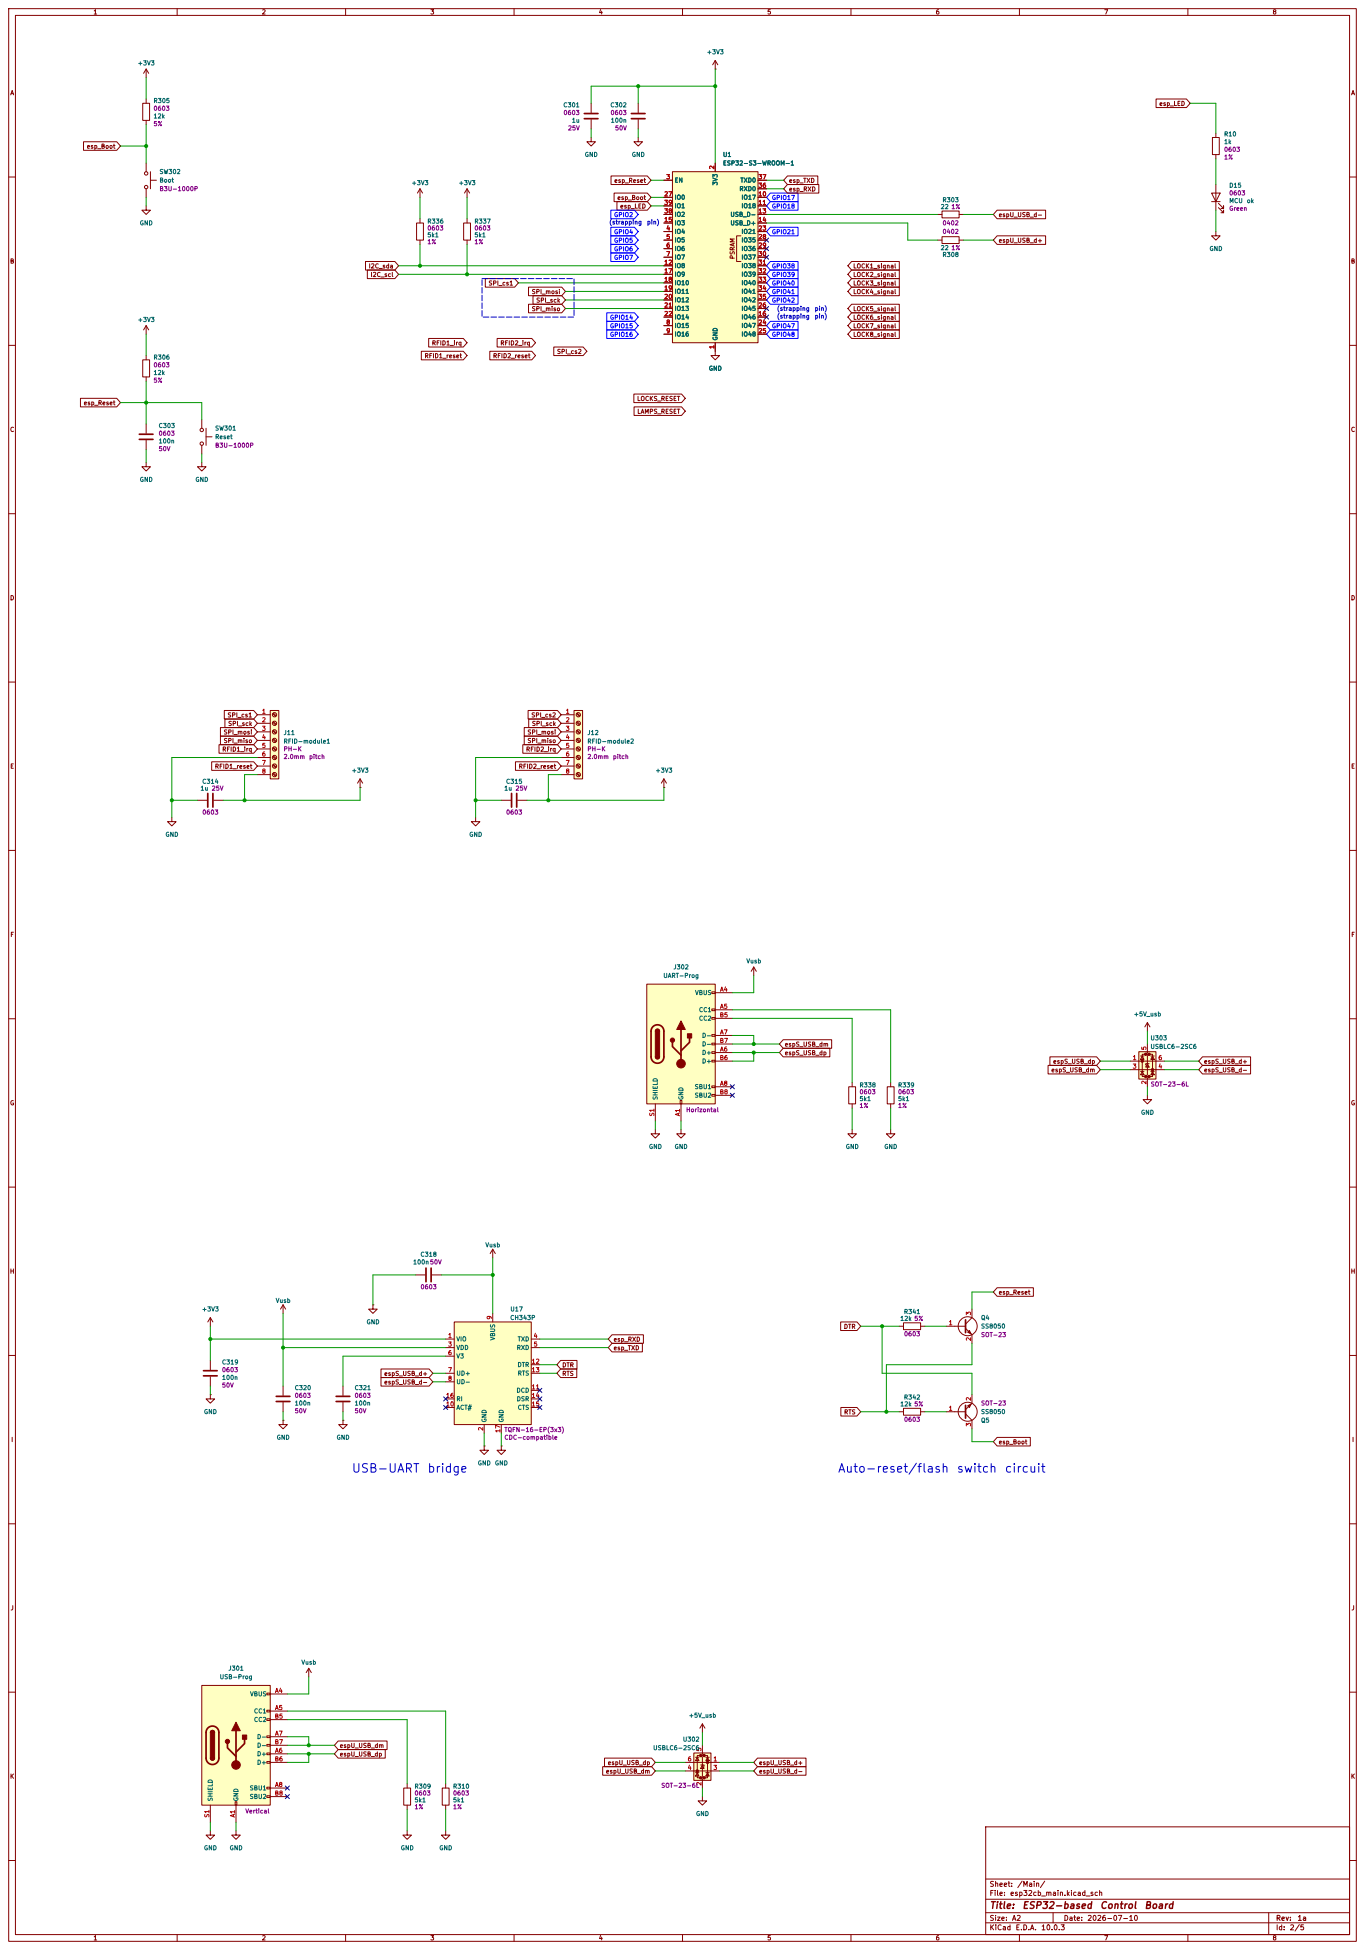
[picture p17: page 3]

Auto-reset/flash switch circuit

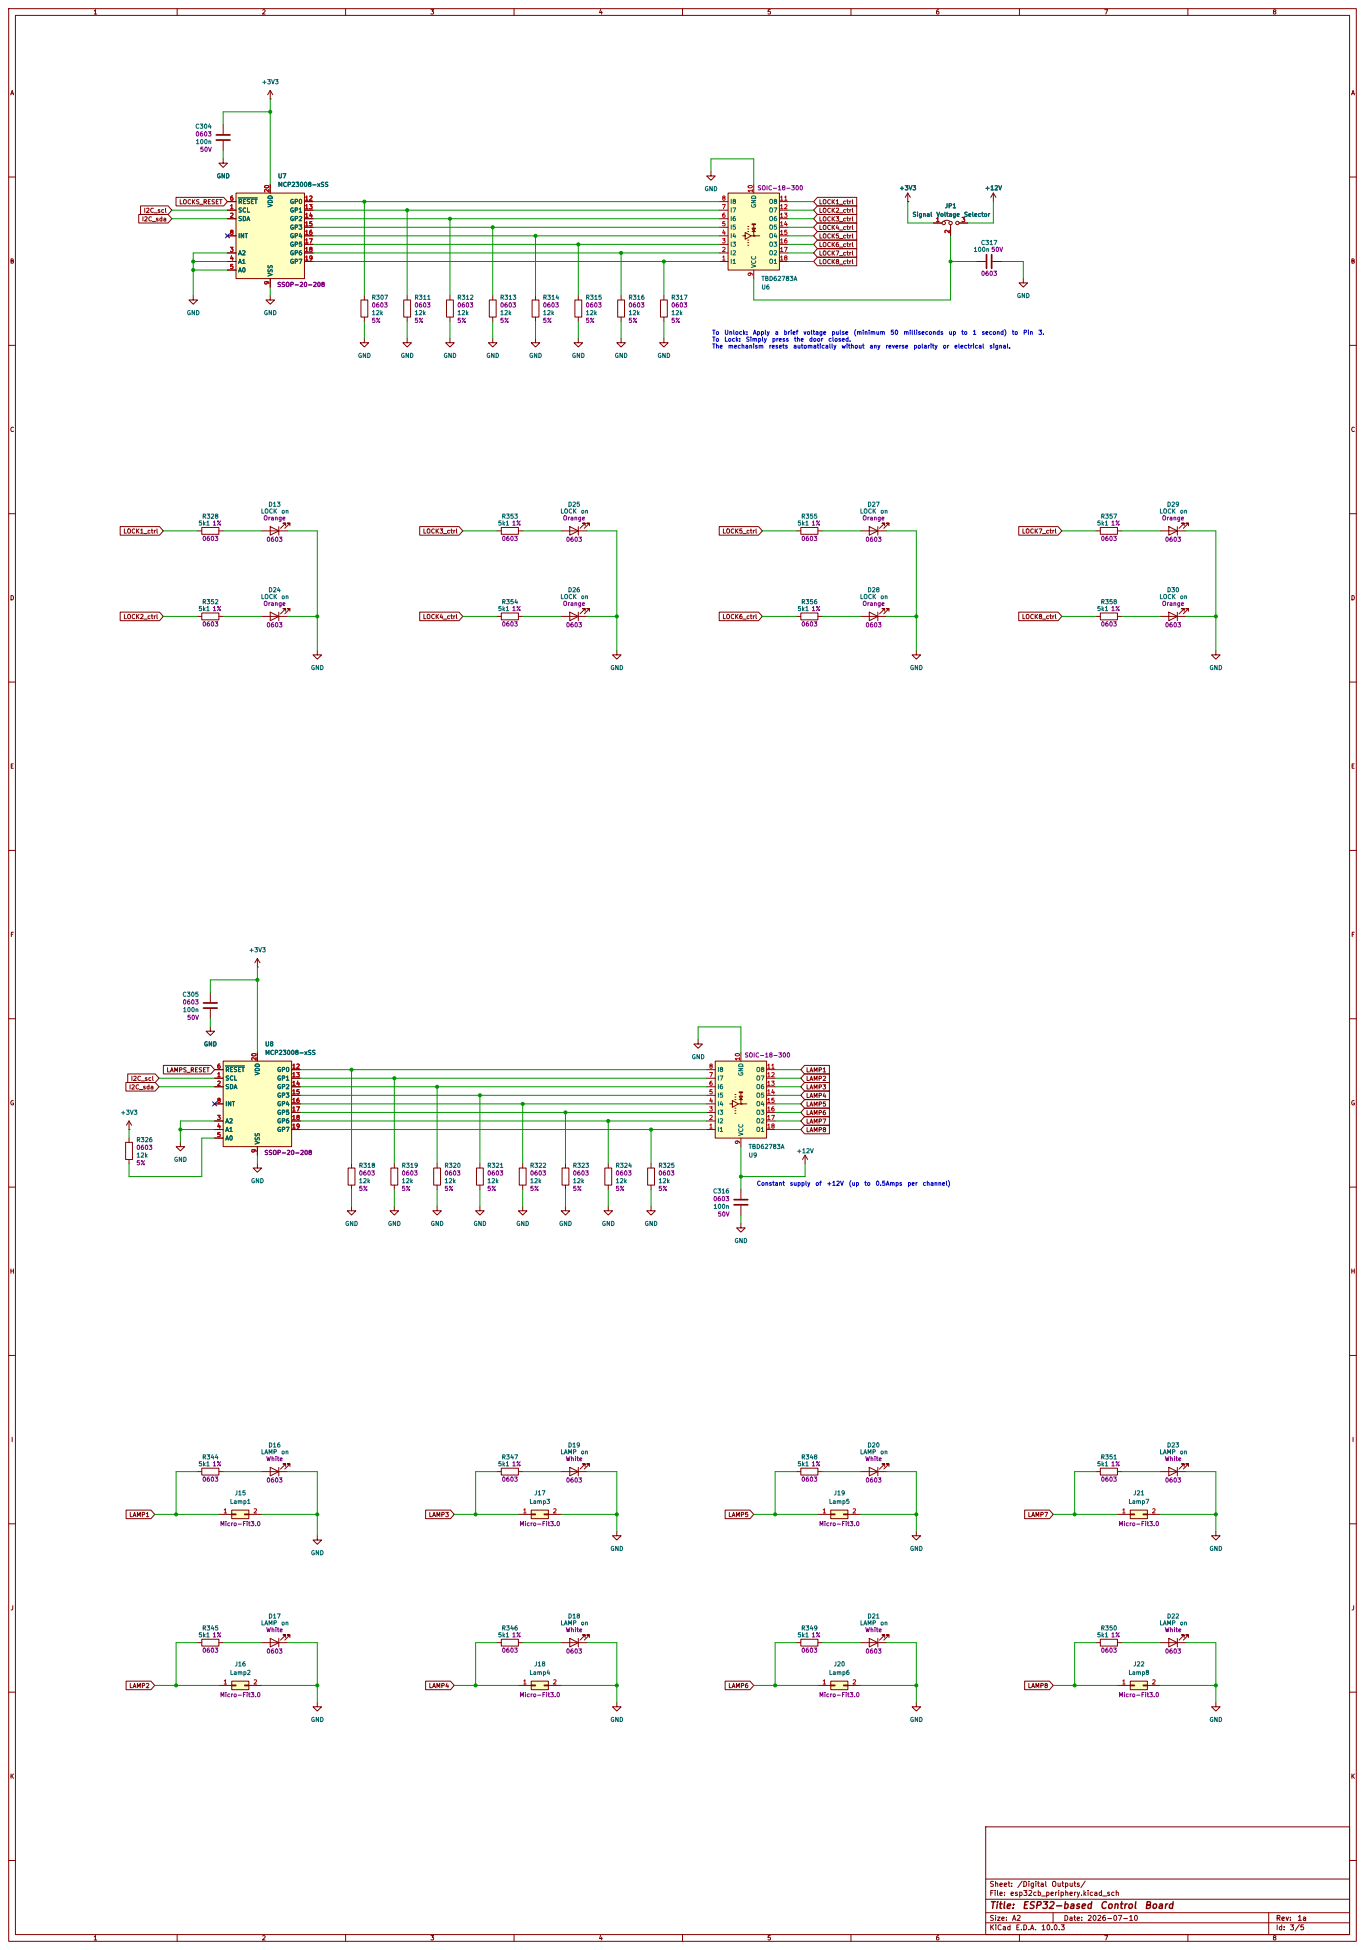
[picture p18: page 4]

I7 7
I6 6
I5 5
I4 4
I3 3
I2 2

To Unlock: Apply a brief voltage pulse (minimum 50 milliseconds up to 1 second) to Pin 3. To Lock: Simply press the door closed. The mechanism resets automatically without any reverse polarity or electrical signal.

Constant supply of +12V (up to 0.5Amps per channel)

LAMP on 0603 White GND

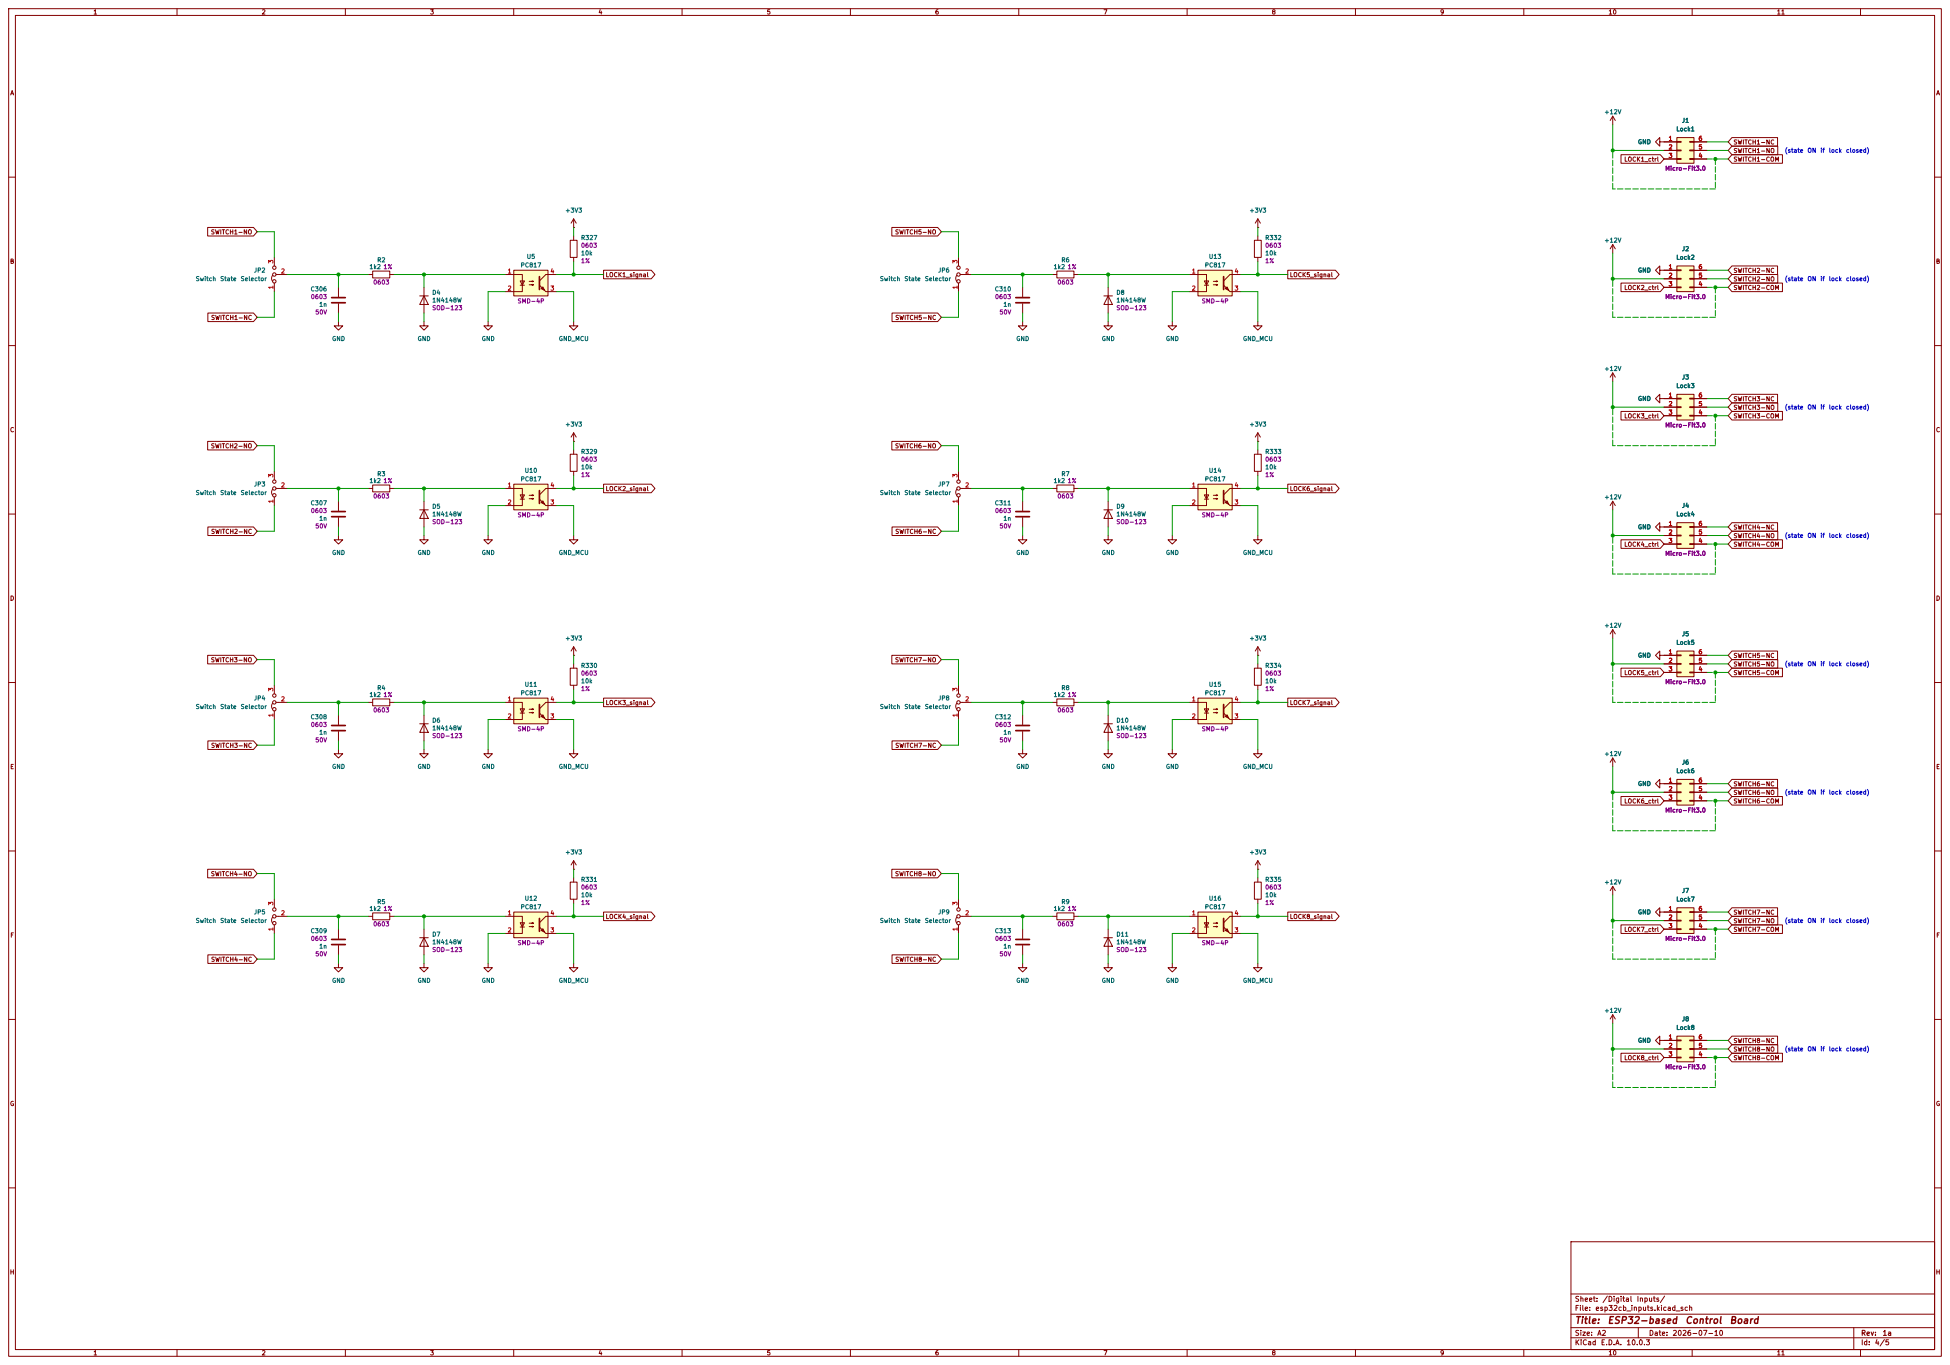
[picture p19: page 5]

6 GND
(state ON if lock closed) GND

(state ON if lock closed)

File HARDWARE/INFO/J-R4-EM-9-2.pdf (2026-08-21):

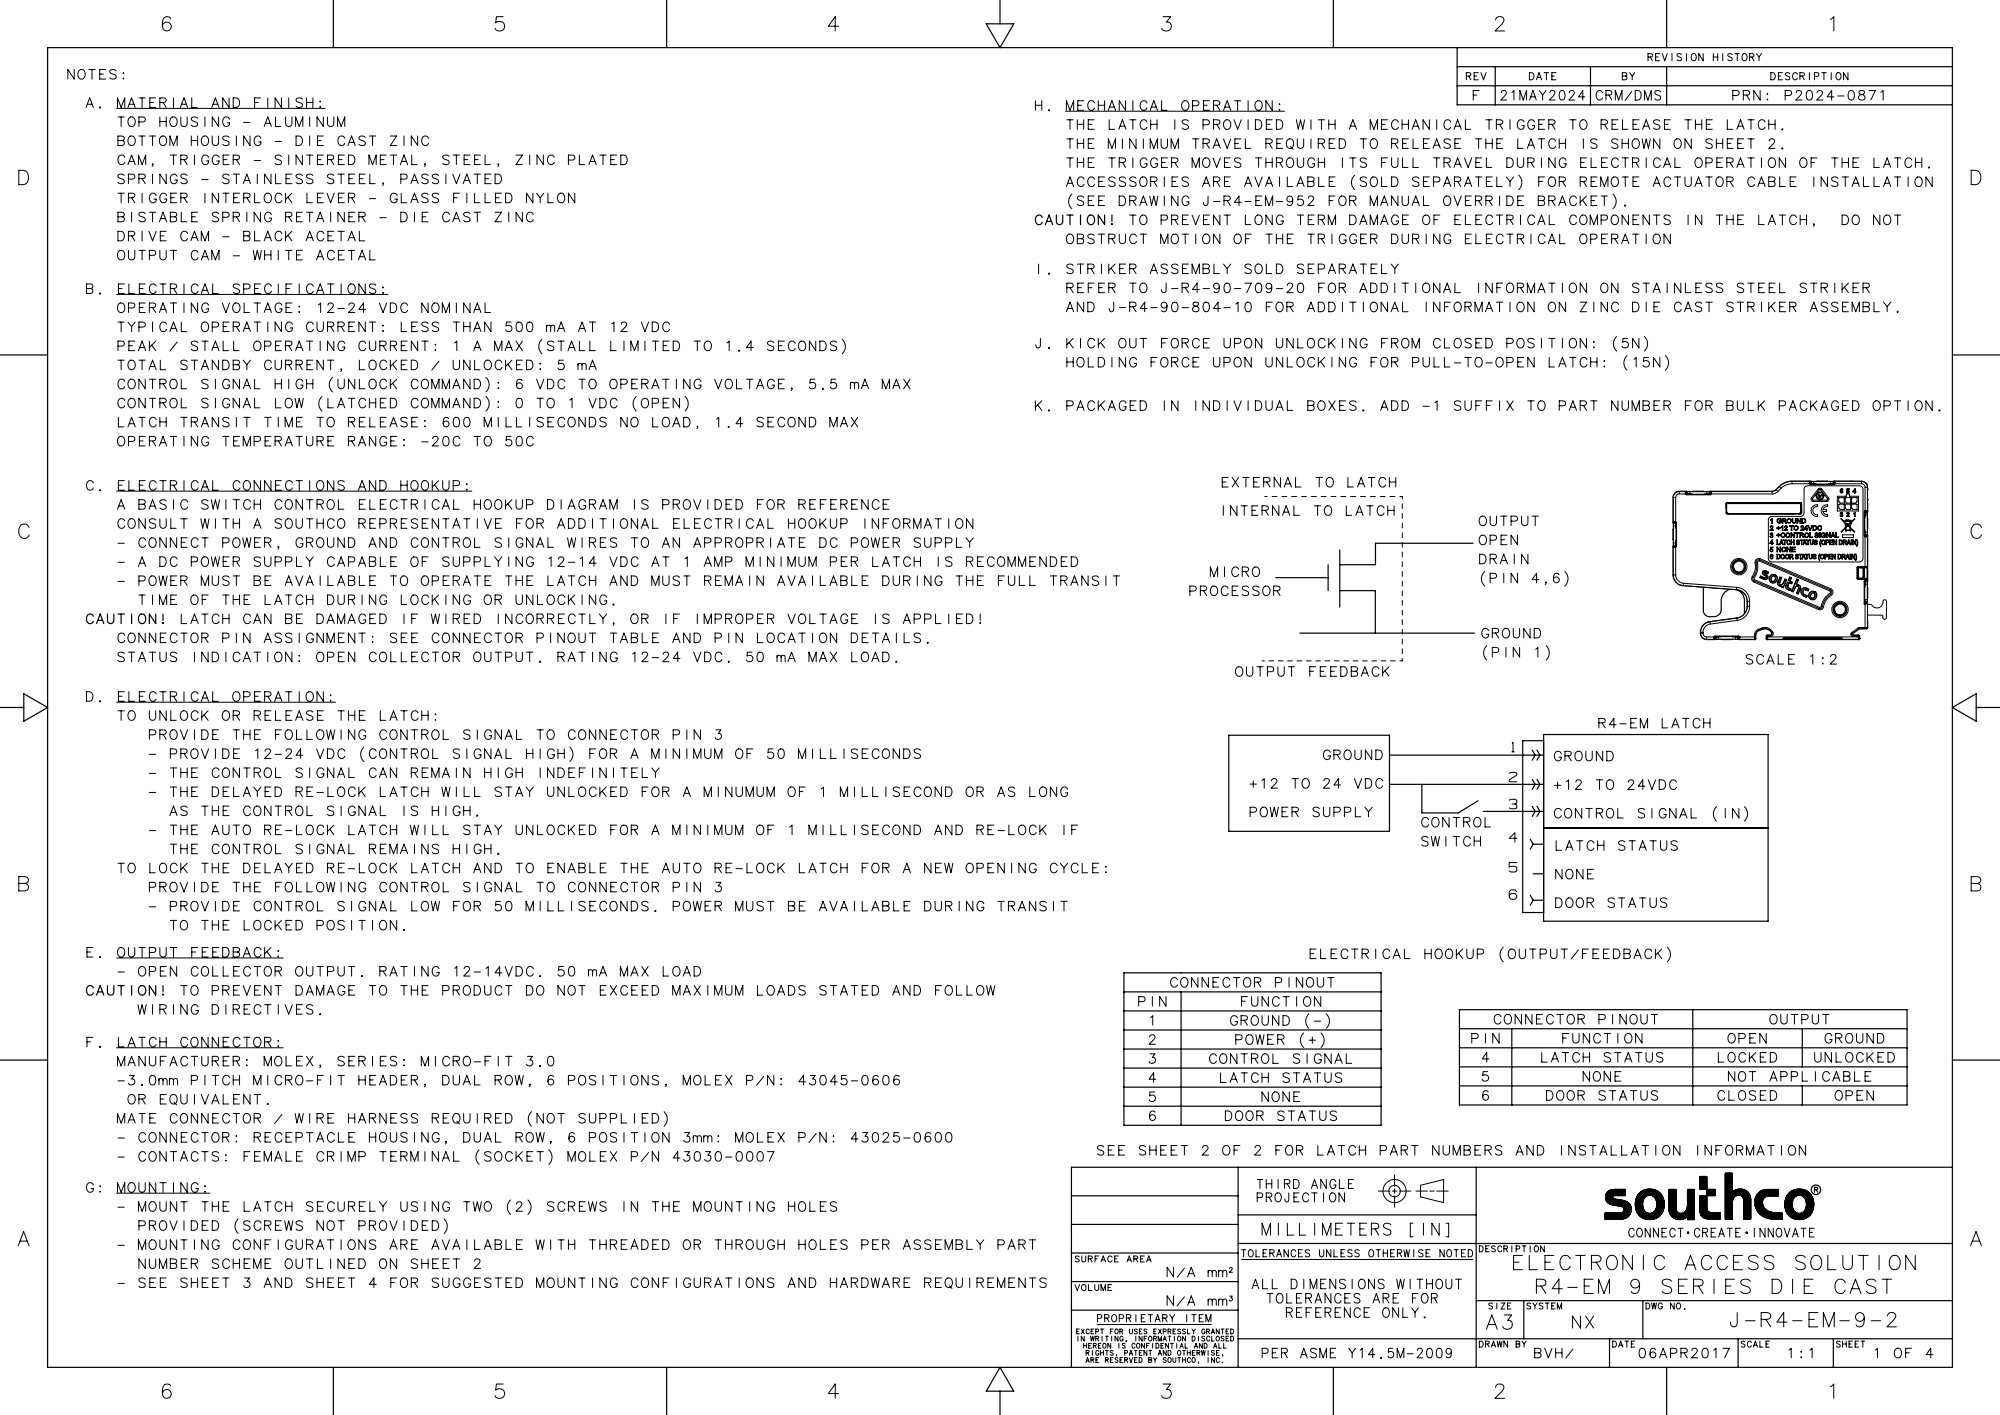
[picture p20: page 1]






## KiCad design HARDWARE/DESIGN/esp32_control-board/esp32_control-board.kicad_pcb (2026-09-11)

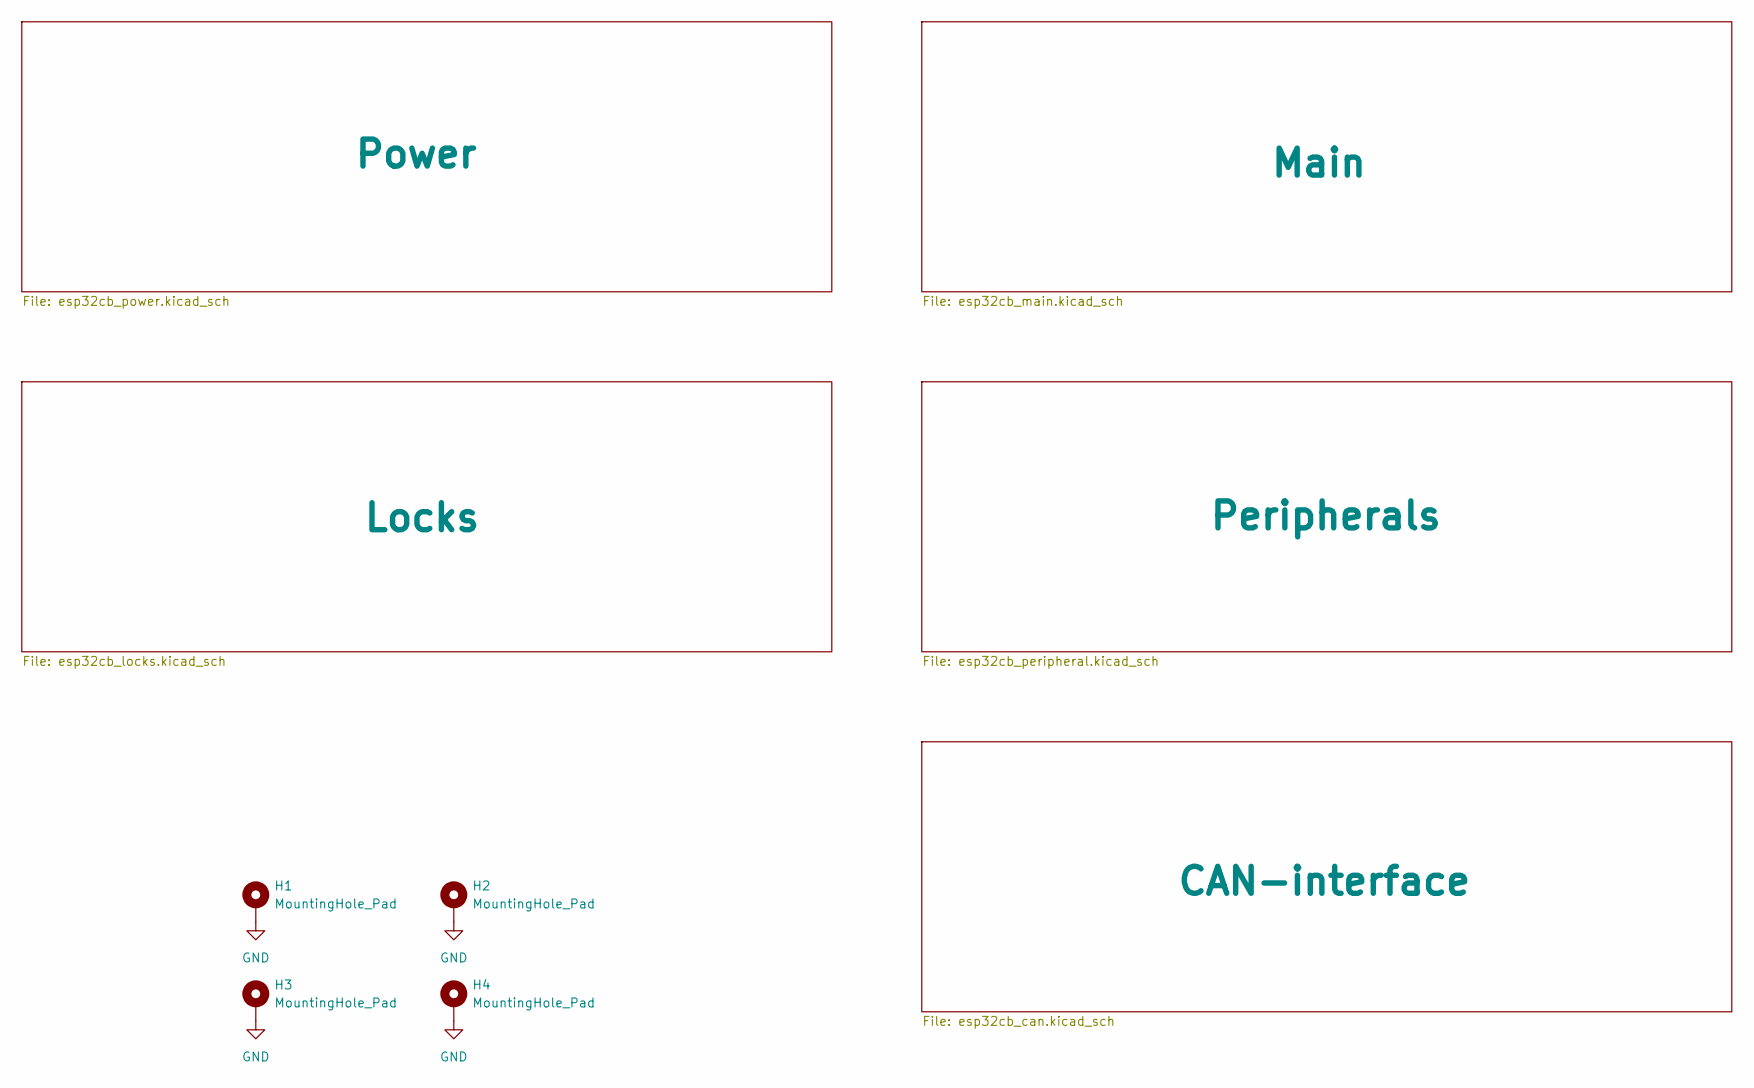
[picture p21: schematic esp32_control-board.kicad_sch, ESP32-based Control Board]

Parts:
H1, H2, H3, H4: MountingHole_Pad; MountingHole_3.2mm_M3_DIN965_Pad_TopBottom

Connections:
GND: H1.1 (1_1), H2.1 (1_1), H3.1 (1_1), H4.1 (1_1); also elsewhere on the board

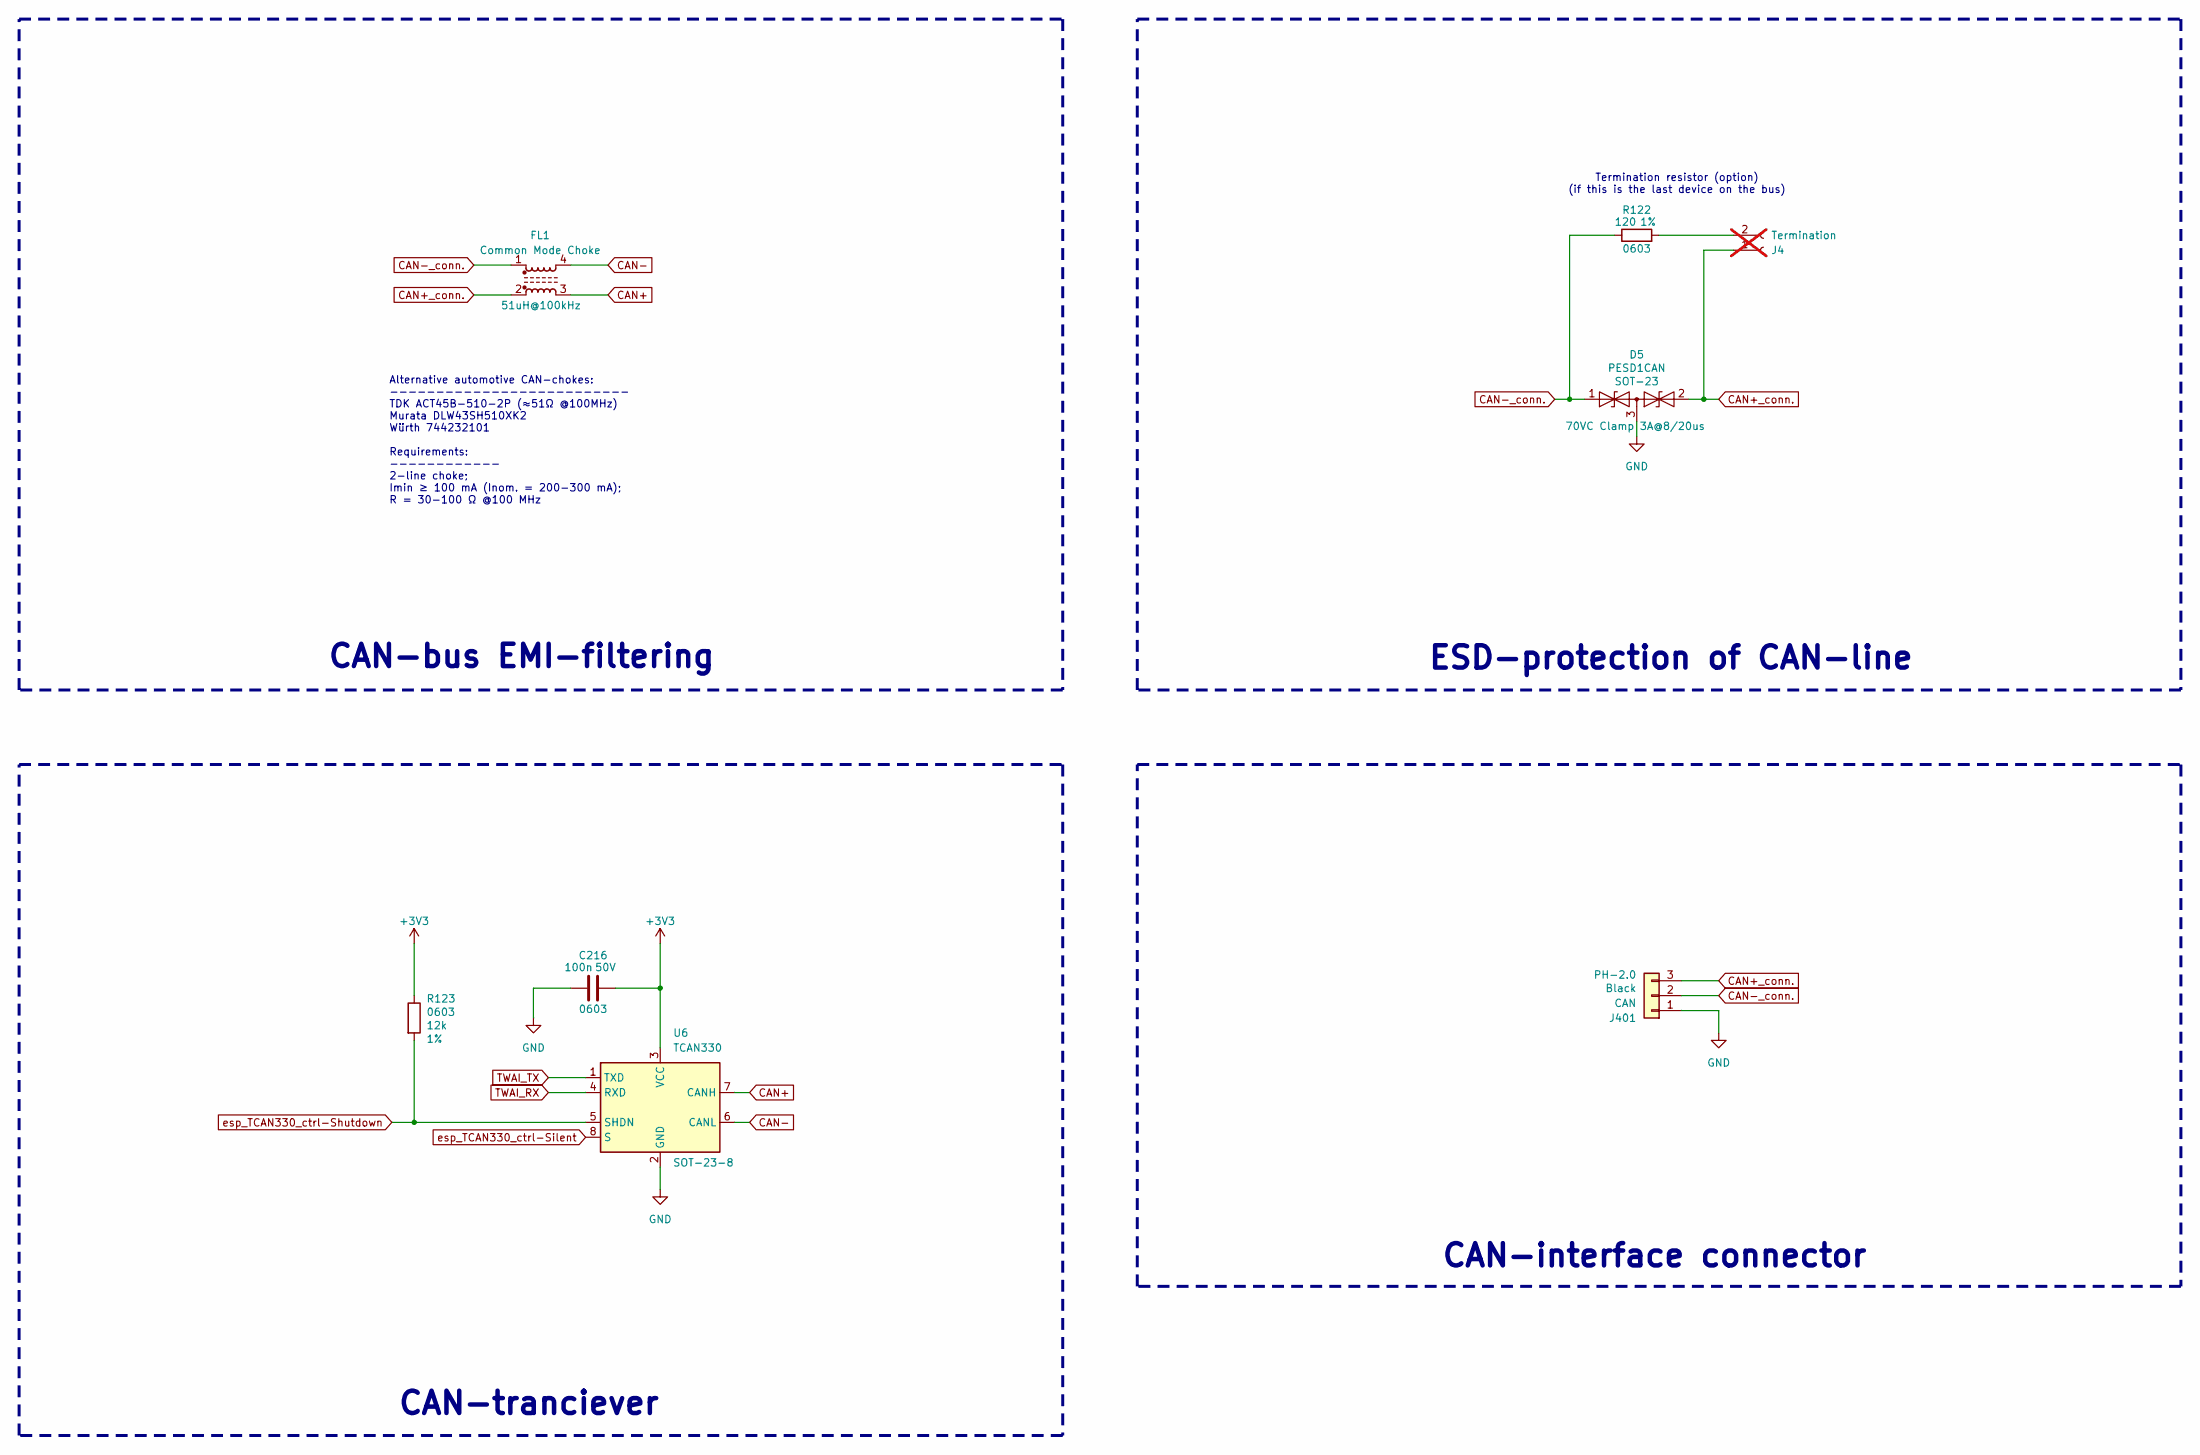
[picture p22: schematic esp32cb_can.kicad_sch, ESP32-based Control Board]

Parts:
C216: 100n; C_0603_1608Metric; LCSC part C1591
D5: PESD1CAN; SOT-23; LCSC part C15771
FL1: Common Mode Choke; C76584_IND-SMD_4P-L4.5-W3.2-TL; LCSC C76584
J4: Termination; PinHeader_1x02_P2.54mm_Horizontal; not fitted
J401: CAN; JST_PH_S3B-PH-K_1x03_P2.00mm_Horizontal
R122: 120; R_0603_1608Metric; LCSC C22787
R123: 12k; R_0603_1608Metric; LCSC C114659
U6: TCAN330; SOT-23-8; LCSC part C2877587

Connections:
+3V3: C216.2, R123.1, U6.3 (VCC); also elsewhere on the board
CAN+: FL1.3, U6.7 (CANH)
CAN+_conn.: D5.2 (A2), FL1.2, J4.1, J401.3
CAN-: FL1.4, U6.6 (CANL)
CAN-_conn.: D5.1 (A1), FL1.1, J401.2, R122.1
GND: C216.1, D5.3 (common), J401.1, U6.2 (GND); also elsewhere on the board
unnamed: J4.2, R122.2
TWAI_RX: U6.4 (RXD); also elsewhere on the board
TWAI_TX: U6.1 (TXD); also elsewhere on the board
esp_TCAN330_ctrl-Shutdown: R123.2, U6.5 (SHDN); also elsewhere on the board
esp_TCAN330_ctrl-Silent: U6.8 (S); also elsewhere on the board

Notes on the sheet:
CAN-tranciever
ESD-protection of CAN-line
CAN-interface connector
Alternative automotive CAN-chokes: -------------------------- TDK ACT45B-510-2P (≈51Ω @100MHz) Murata DLW43SH510XK2 Würth 744232101 Requirements: ------------ 2-line choke; Imin ≥ 100 mА (Inom. = 200-300 mА); R = 30-100 Ω @100 MHz
Termination resistor (option) (if this is the last device on the bus)
CAN-bus EMI-filtering

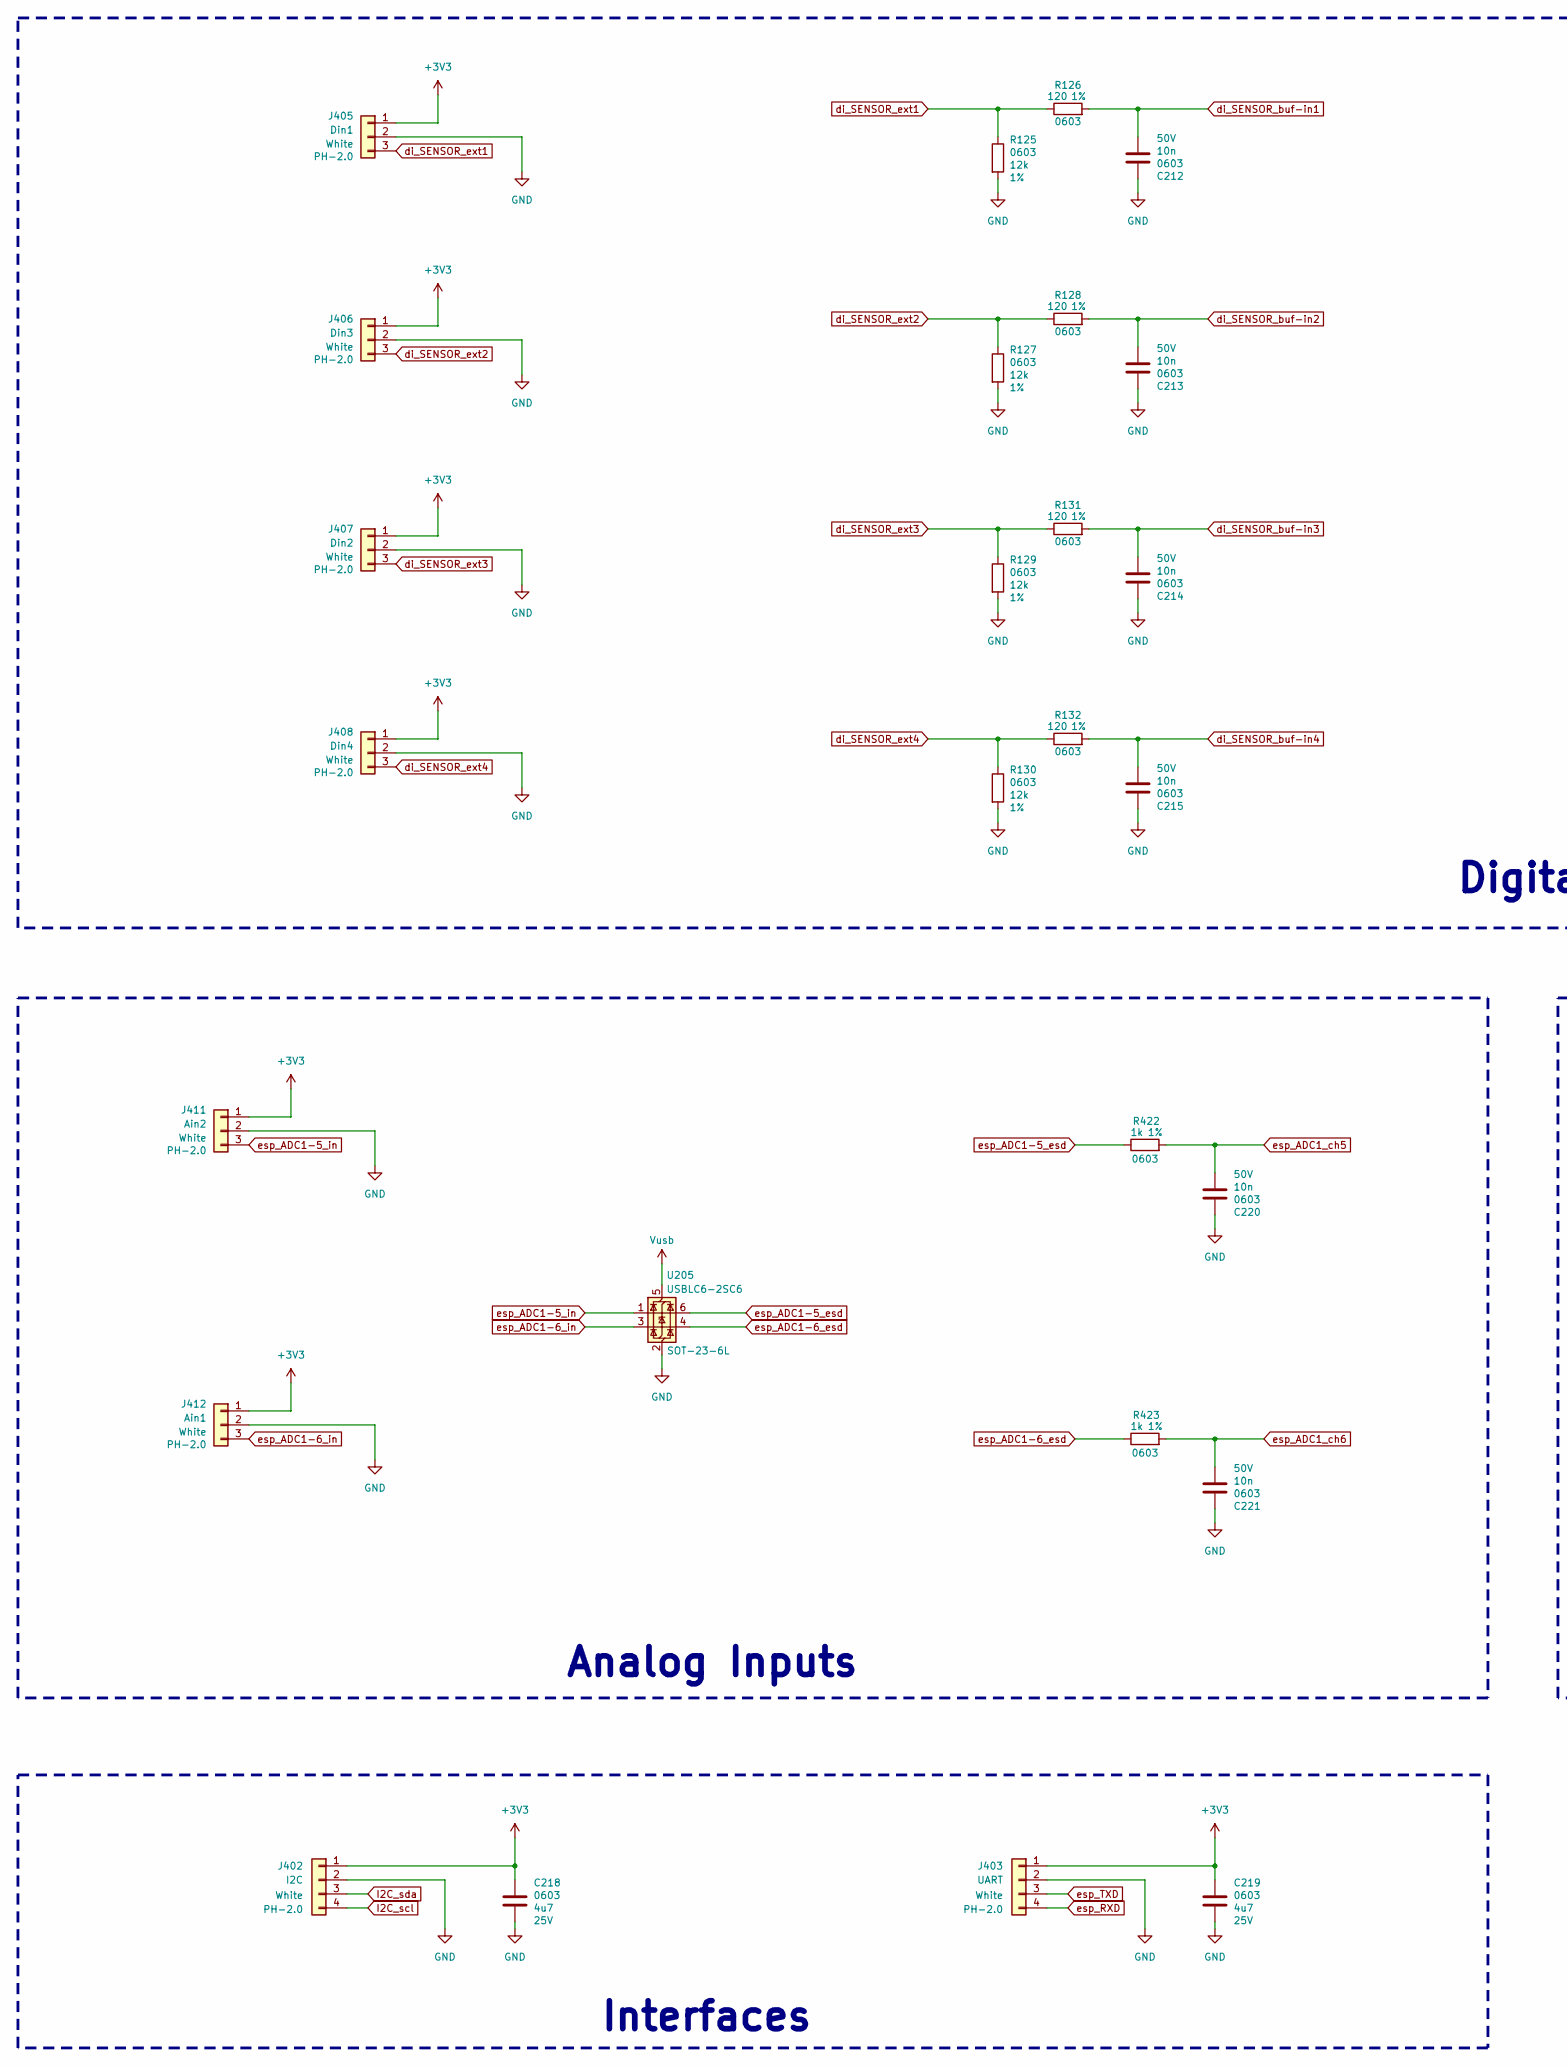
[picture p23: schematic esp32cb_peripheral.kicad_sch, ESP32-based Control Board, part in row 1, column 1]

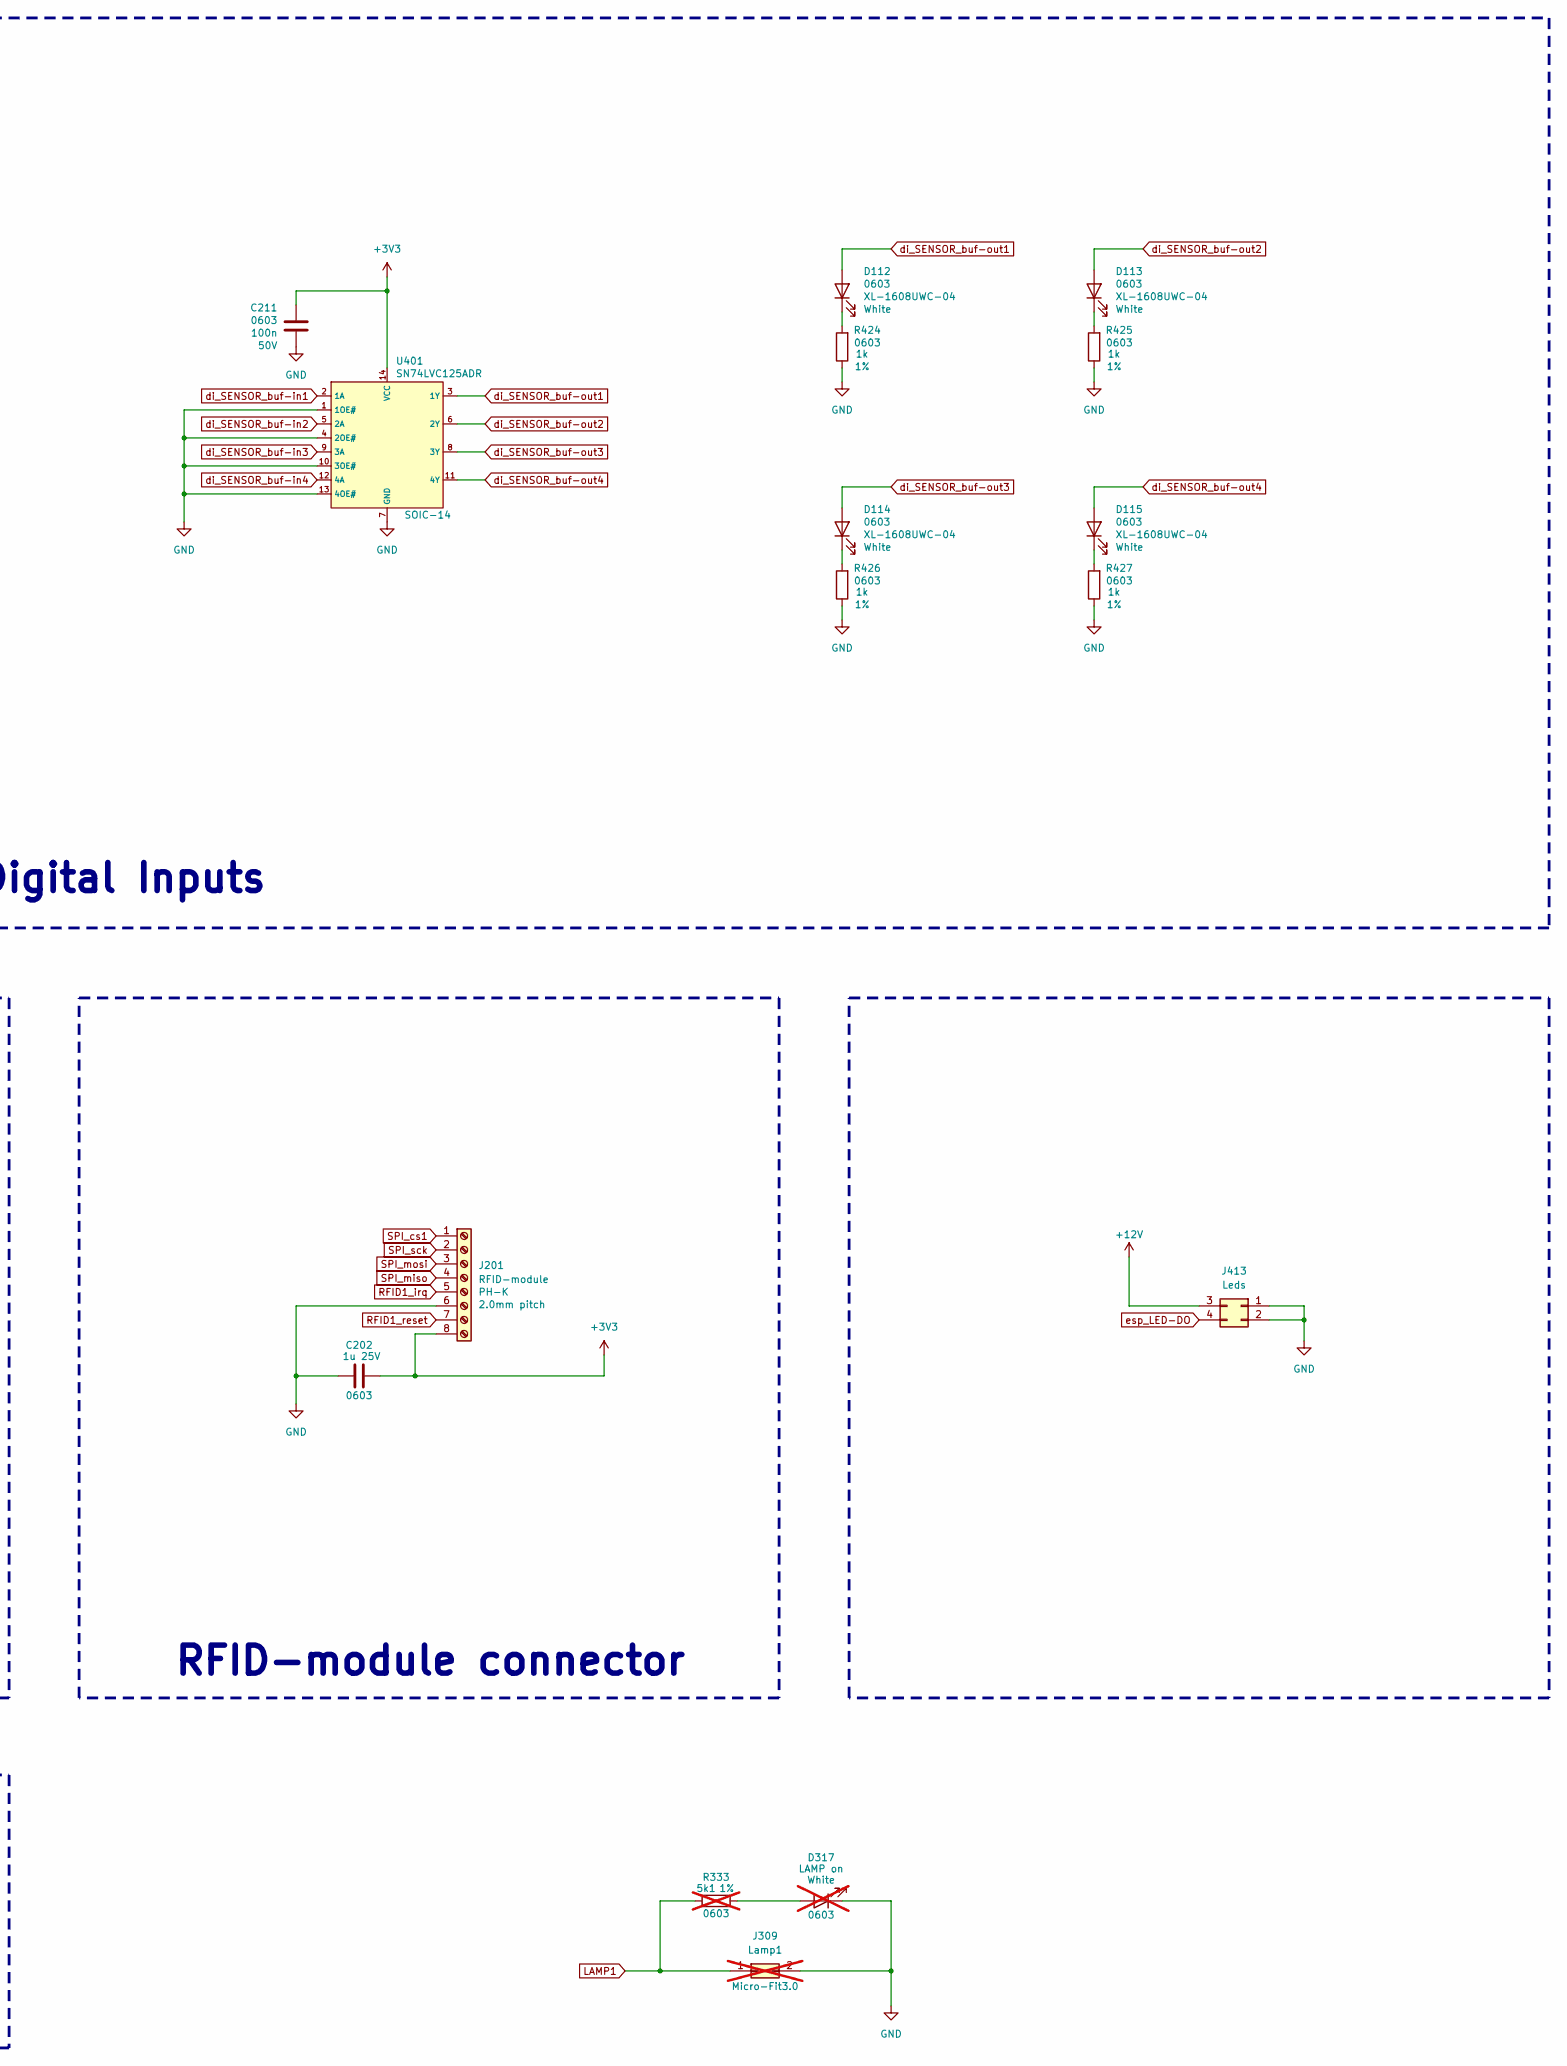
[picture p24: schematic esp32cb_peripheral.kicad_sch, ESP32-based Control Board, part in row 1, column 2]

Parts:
C202: 1u; C_0603_1608Metric; LCSC part C29936
C211: 100n; C_0603_1608Metric; LCSC part C1591
C212, C213, C214, C215, C220, C221: 10n; C_0603_1608Metric; LCSC C1589
C218, C219: 4u7; C_0805_2012Metric; LCSC C98195
D112, D113, D114, D115: XL-1608UWC-04; LED_0603_1608Metric; LCSC part C965808
D317: LAMP on; LED_0603_1608Metric; LCSC C965808; not fitted
J201: RFID-module; JST_PH_S8B-PH-K_1x08_P2.00mm_Horizontal; LCSC C157974
J309: Lamp1; Molex_Micro-Fit_3.0_43045-0200_2x01_P3.00mm_Horizontal; LCSC C122431; not fitted
J402: I2C; JST_PH_B4B-PH-K_1x04_P2.00mm_Vertical; LCSC C131334
J403: UART; JST_PH_B4B-PH-K_1x04_P2.00mm_Vertical; LCSC C131334
J405: Din1; JST_PH_S3B-PH-K_1x03_P2.00mm_Horizontal
J406: Din3; JST_PH_B3B-PH-K_1x03_P2.00mm_Vertical; LCSC C131339
J407: Din2; JST_PH_S3B-PH-K_1x03_P2.00mm_Horizontal
J408: Din4; JST_PH_B3B-PH-K_1x03_P2.00mm_Vertical; LCSC C131339
J411: Ain2; JST_PH_B3B-PH-K_1x03_P2.00mm_Vertical; LCSC C131339
J412: Ain1; JST_PH_S3B-PH-K_1x03_P2.00mm_Horizontal
J413: Leds; Molex_Micro-Fit_3.0_43045-0400_2x02_P3.00mm_Horizontal; LCSC C122413
R125, R127, R129, R130: 12k; R_0603_1608Metric; LCSC C114659
R126, R128, R131, R132: 120; R_0603_1608Metric; LCSC C22787
R333: 5k1; R_0603_1608Metric; LCSC part C2907044; not fitted
R422, R423, R424, R425, R426, R427: 1k; R_0603_1608Metric; LCSC part C21190
U205: USBLC6-2SC6; SOT-23-6; LCSC part C7519
U401: SN74LVC125ADR; SOIC-14_3.9x8.7mm_P1.27mm; LCSC C7661

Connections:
+3V3: C202.1, C211.2, C218.2, C219.2, J201.8, J402.1, J403.1, J405.1, J406.1, J407.1, J408.1, J411.1, J412.1, U401.14 (VCC); also elsewhere on the board
+12V: J413.3; also elsewhere on the board
GND: C202.2, C211.1, C212.2, C213.2, C214.2, C215.2, C218.1, C219.1, C220.2, C221.2, D317.1 (K), J201.6, J309.2, J402.2, J403.2, J405.2, J406.2, J407.2, J408.2, J411.2, J412.2, J413.1, J413.2, R125.2, R127.2, R129.2, R130.2, R424.1, R425.1, R426.1, R427.1, U205.2 (GND), U401.1 (1OE#), U401.4 (2OE#), U401.7 (GND), U401.10 (3OE#), U401.13 (4OE#); also elsewhere on the board
I2C_scl: J402.4; also elsewhere on the board
I2C_sda: J402.3; also elsewhere on the board
unnamed: D112.1 (K), R424.2
unnamed: D113.1 (K), R425.2
unnamed: D114.1 (K), R426.2
unnamed: D115.1 (K), R427.2
unnamed: D317.2 (A), R333.1
unnamed: J309.1, R333.2
RFID1_irq: J201.5; also elsewhere on the board
RFID1_reset: J201.7; also elsewhere on the board
SPI_cs1: J201.1; also elsewhere on the board
SPI_miso: J201.4; also elsewhere on the board
SPI_mosi: J201.3; also elsewhere on the board
SPI_sck: J201.2; also elsewhere on the board
Vusb: U205.5 (VBUS); also elsewhere on the board
di_SENSOR_buf-in1: C212.1, R126.2, U401.2 (1A)
di_SENSOR_buf-in2: C213.1, R128.2, U401.5 (2A)
di_SENSOR_buf-in3: C214.1, R131.2, U401.9 (3A)
di_SENSOR_buf-in4: C215.1, R132.2, U401.12 (4A)
di_SENSOR_buf-out1: D112.2 (A), U401.3 (1Y)
di_SENSOR_buf-out2: D113.2 (A), U401.6 (2Y)
di_SENSOR_buf-out3: D114.2 (A), U401.8 (3Y)
di_SENSOR_buf-out4: D115.2 (A), U401.11 (4Y)
di_SENSOR_ext1: J405.3, R125.1, R126.1
di_SENSOR_ext2: J406.3, R127.1, R128.1
di_SENSOR_ext3: J407.3, R129.1, R131.1
di_SENSOR_ext4: J408.3, R130.1, R132.1
esp_ADC1-5_esd: R422.1, U205.6 (I/O1)
esp_ADC1-5_in: J411.3, U205.1 (I/O1)
esp_ADC1-6_esd: R423.1, U205.4 (I/O2)
esp_ADC1-6_in: J412.3, U205.3 (I/O2)
esp_ADC1_ch5: C220.1, R422.2; also elsewhere on the board
esp_ADC1_ch6: C221.1, R423.2; also elsewhere on the board
esp_LED-DO: J413.4; also elsewhere on the board
esp_RXD: J403.4; also elsewhere on the board
esp_TXD: J403.3; also elsewhere on the board

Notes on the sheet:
Interfaces
Analog Inputs
RFID-module connector
Digital Inputs

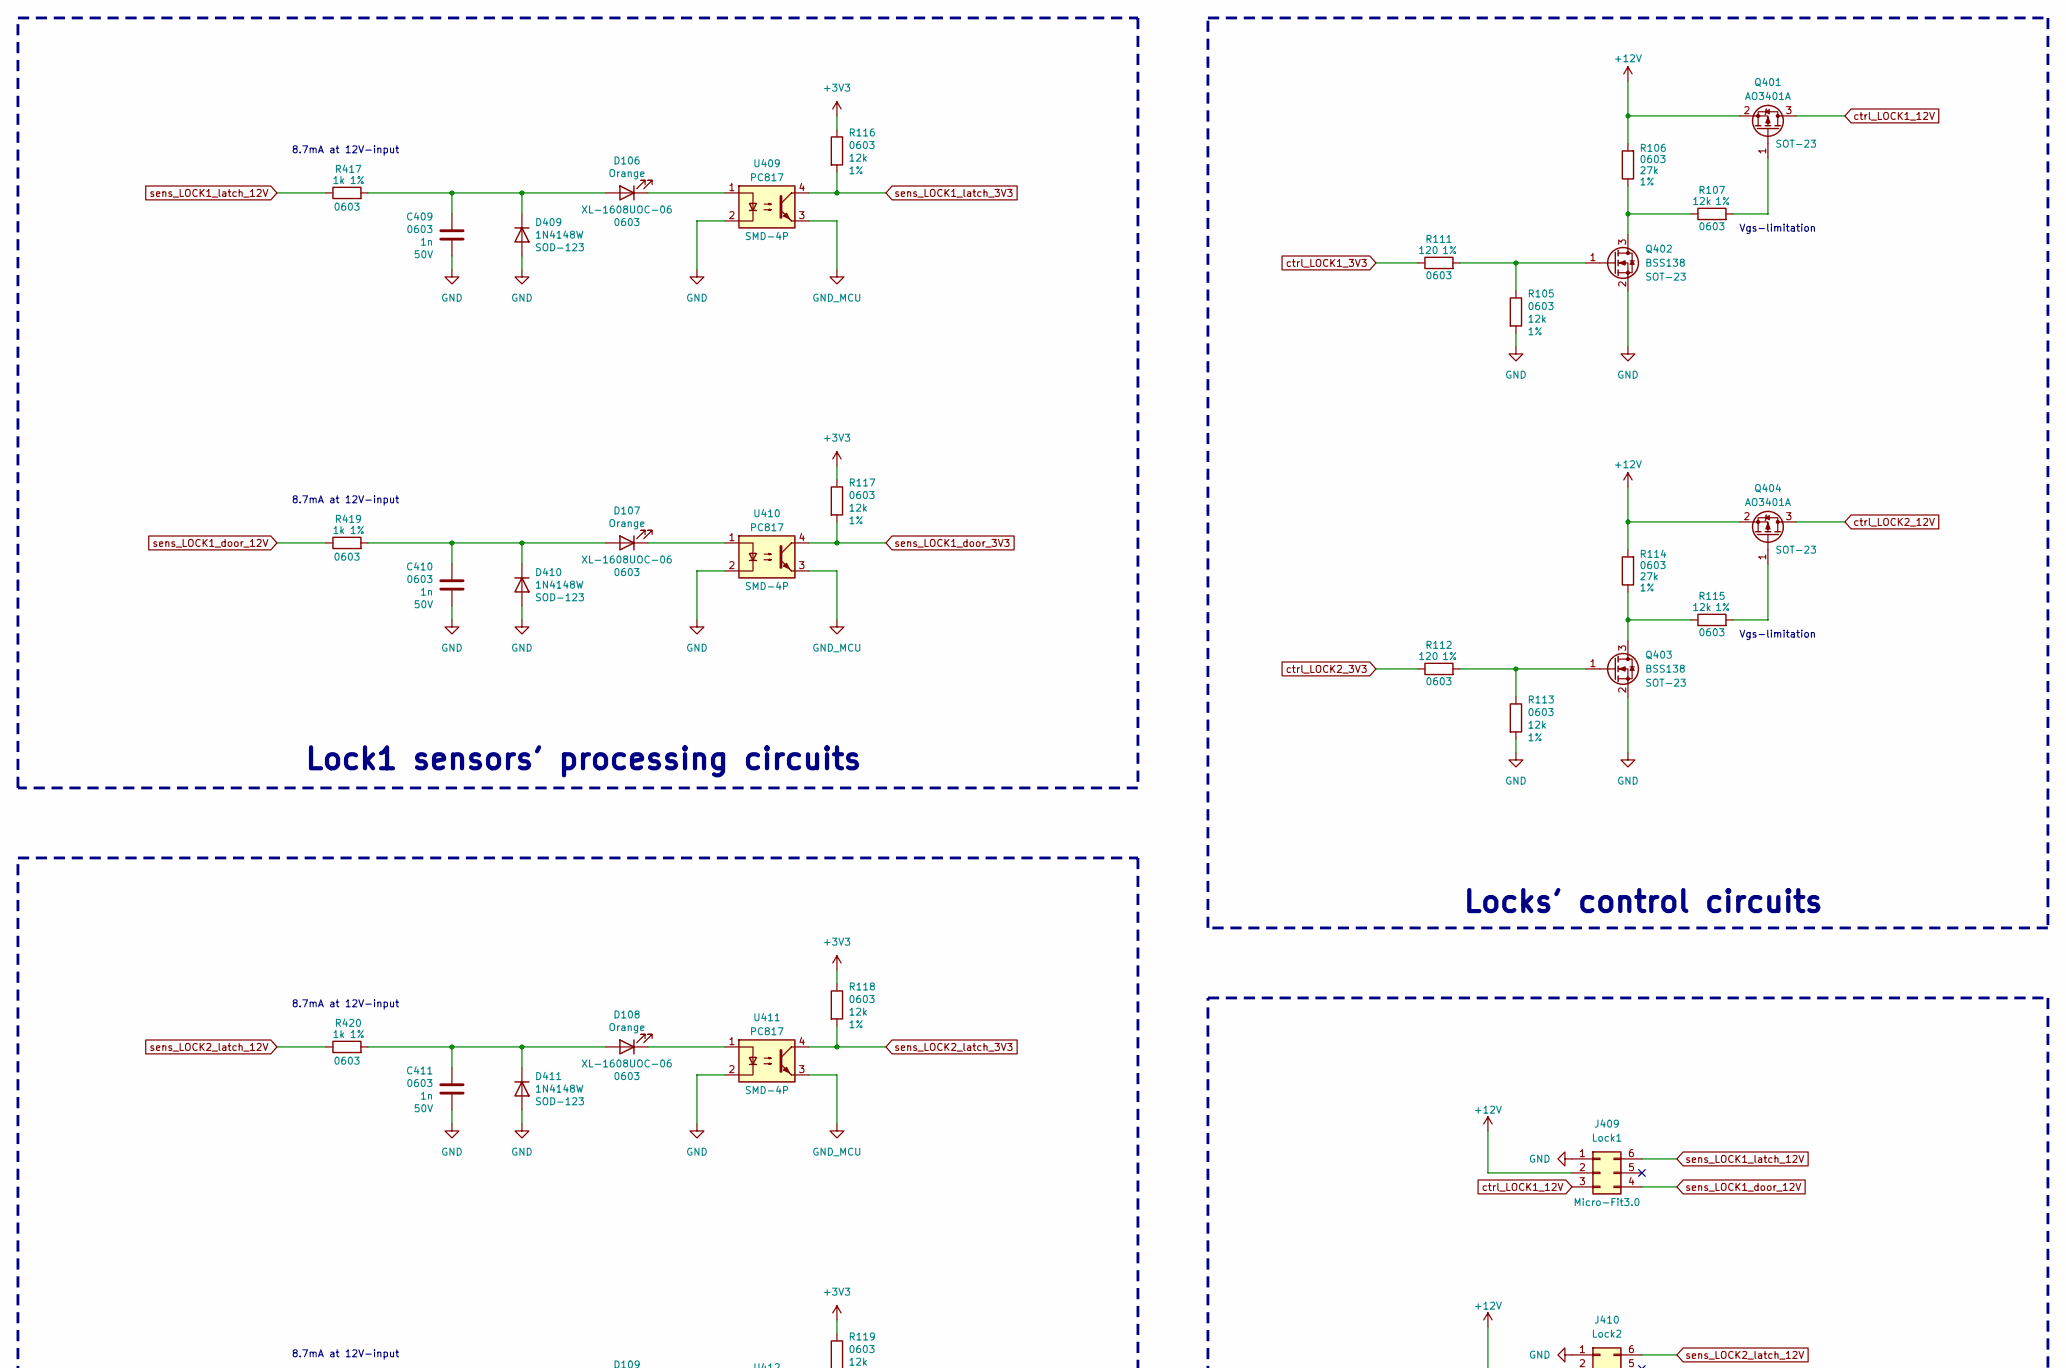
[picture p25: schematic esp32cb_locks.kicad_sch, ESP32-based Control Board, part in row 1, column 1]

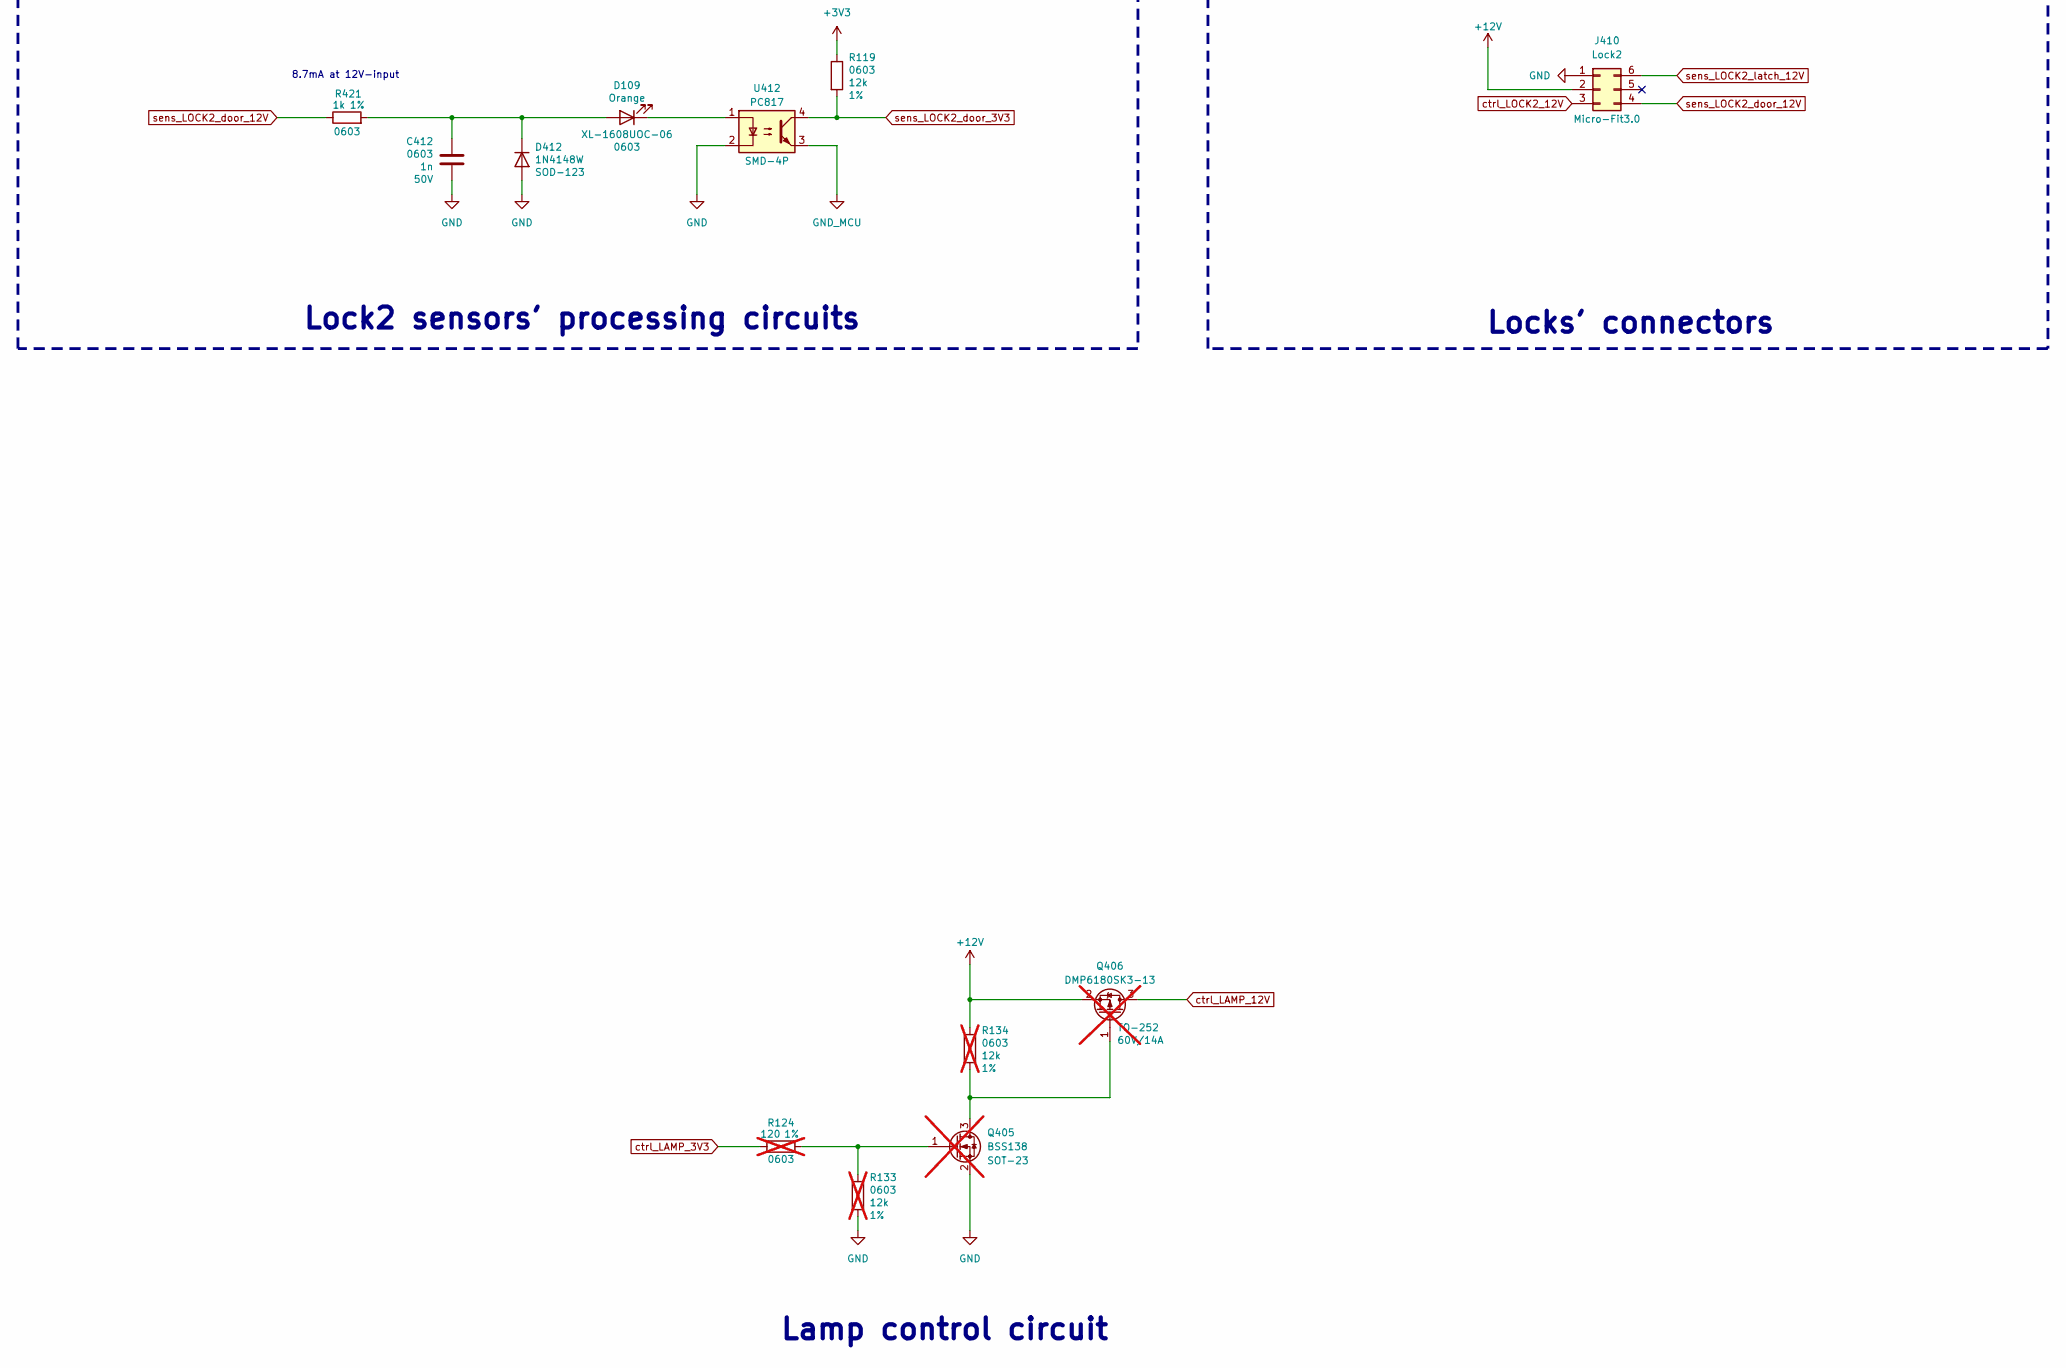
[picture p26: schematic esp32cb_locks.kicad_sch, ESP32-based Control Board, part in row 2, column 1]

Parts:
C409, C410, C411, C412: 1n; C_0603_1608Metric; LCSC C106246
D106, D107, D108, D109: XL-1608UOC-06; LED_0603_1608Metric; LCSC C965800
D409, D410, D411, D412: 1N4148W; D_SOD-123; LCSC C917030
J409: Lock1; Molex_Micro-Fit_3.0_43045-0600_2x03_P3.00mm_Horizontal; LCSC C127367
J410: Lock2; Molex_Micro-Fit_3.0_43045-0600_2x03_P3.00mm_Horizontal; LCSC C127367
Q401, Q404: AO3401A; SOT-23; LCSC C2938368
Q402, Q403: BSS138; SOT-23; LCSC C52895
Q405: BSS138; SOT-23; LCSC C52895; not fitted
Q406: DMP6180SK3-13; TO-252-2; LCSC C93034; not fitted
R105, R107, R113, R115, R116, R117, R118, R119: 12k; R_0603_1608Metric; LCSC C114659
R106, R114: 27k; R_0603_1608Metric; LCSC C114614
R111, R112: 120; R_0603_1608Metric; LCSC C22787
R124: 120; R_0603_1608Metric; LCSC C22787; not fitted
R133, R134: 12k; R_0603_1608Metric; LCSC C114659; not fitted
R417, R419, R420, R421: 1k; R_0603_1608Metric; LCSC part C21190
U409, U410, U411, U412: PC817; DIP-4_W7.62mm_SMDSocket_SmallPads; LCSC C66405

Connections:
+3V3: R116.1, R117.1, R118.1, R119.1; also elsewhere on the board
+12V: J409.2, J410.2, Q401.2 (S), Q404.2 (S), Q406.2 (S), R106.2, R114.2, R134.1; also elsewhere on the board
GND: C409.1, C410.1, C411.1, C412.1, D409.2 (A), D410.2 (A), D411.2 (A), D412.2 (A), J409.1, J410.1, Q402.2 (S), Q403.2 (S), Q405.2 (S), R105.2, R113.2, R133.2, U409.2, U410.2, U411.2, U412.2; also elsewhere on the board
GND_MCU: U409.3, U410.3, U411.3, U412.3; also elsewhere on the board
unnamed: C409.2, D106.2 (A), D409.1 (K), R417.2
unnamed: D106.1 (K), U409.1
unnamed: C410.2, D107.2 (A), D410.1 (K), R419.2
unnamed: D107.1 (K), U410.1
unnamed: C411.2, D108.2 (A), D411.1 (K), R420.2
unnamed: D108.1 (K), U411.1
unnamed: C412.2, D109.2 (A), D412.1 (K), R421.2
unnamed: D109.1 (K), U412.1
unnamed: Q401.1 (G), R107.2
unnamed: Q402.3 (D), R106.1, R107.1
unnamed: Q402.1 (G), R105.1, R111.2
unnamed: Q403.3 (D), R114.1, R115.1
unnamed: Q403.1 (G), R112.2, R113.1
unnamed: Q404.1 (G), R115.2
unnamed: Q405.1 (G), R124.2, R133.1
unnamed: Q405.3 (D), Q406.1 (G), R134.2
ctrl_LOCK1_3V3: R111.1; also elsewhere on the board
ctrl_LOCK1_12V: J409.3, Q401.3 (D)
ctrl_LOCK2_3V3: R112.1; also elsewhere on the board
ctrl_LOCK2_12V: J410.3, Q404.3 (D)
sens_LOCK1_door_3V3: R117.2, U410.4; also elsewhere on the board
sens_LOCK1_door_12V: J409.4, R419.1
sens_LOCK1_latch_3V3: R116.2, U409.4; also elsewhere on the board
sens_LOCK1_latch_12V: J409.6, R417.1
sens_LOCK2_door_3V3: R119.2, U412.4; also elsewhere on the board
sens_LOCK2_door_12V: J410.4, R421.1
sens_LOCK2_latch_3V3: R118.2, U411.4; also elsewhere on the board
sens_LOCK2_latch_12V: J410.6, R420.1

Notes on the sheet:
Vgs-limitation
8.7mA at 12V-input
Locks' control circuits
Locks' connectors
Lock1 sensors' processing circuits
Lock2 sensors' processing circuits
Lamp control circuit

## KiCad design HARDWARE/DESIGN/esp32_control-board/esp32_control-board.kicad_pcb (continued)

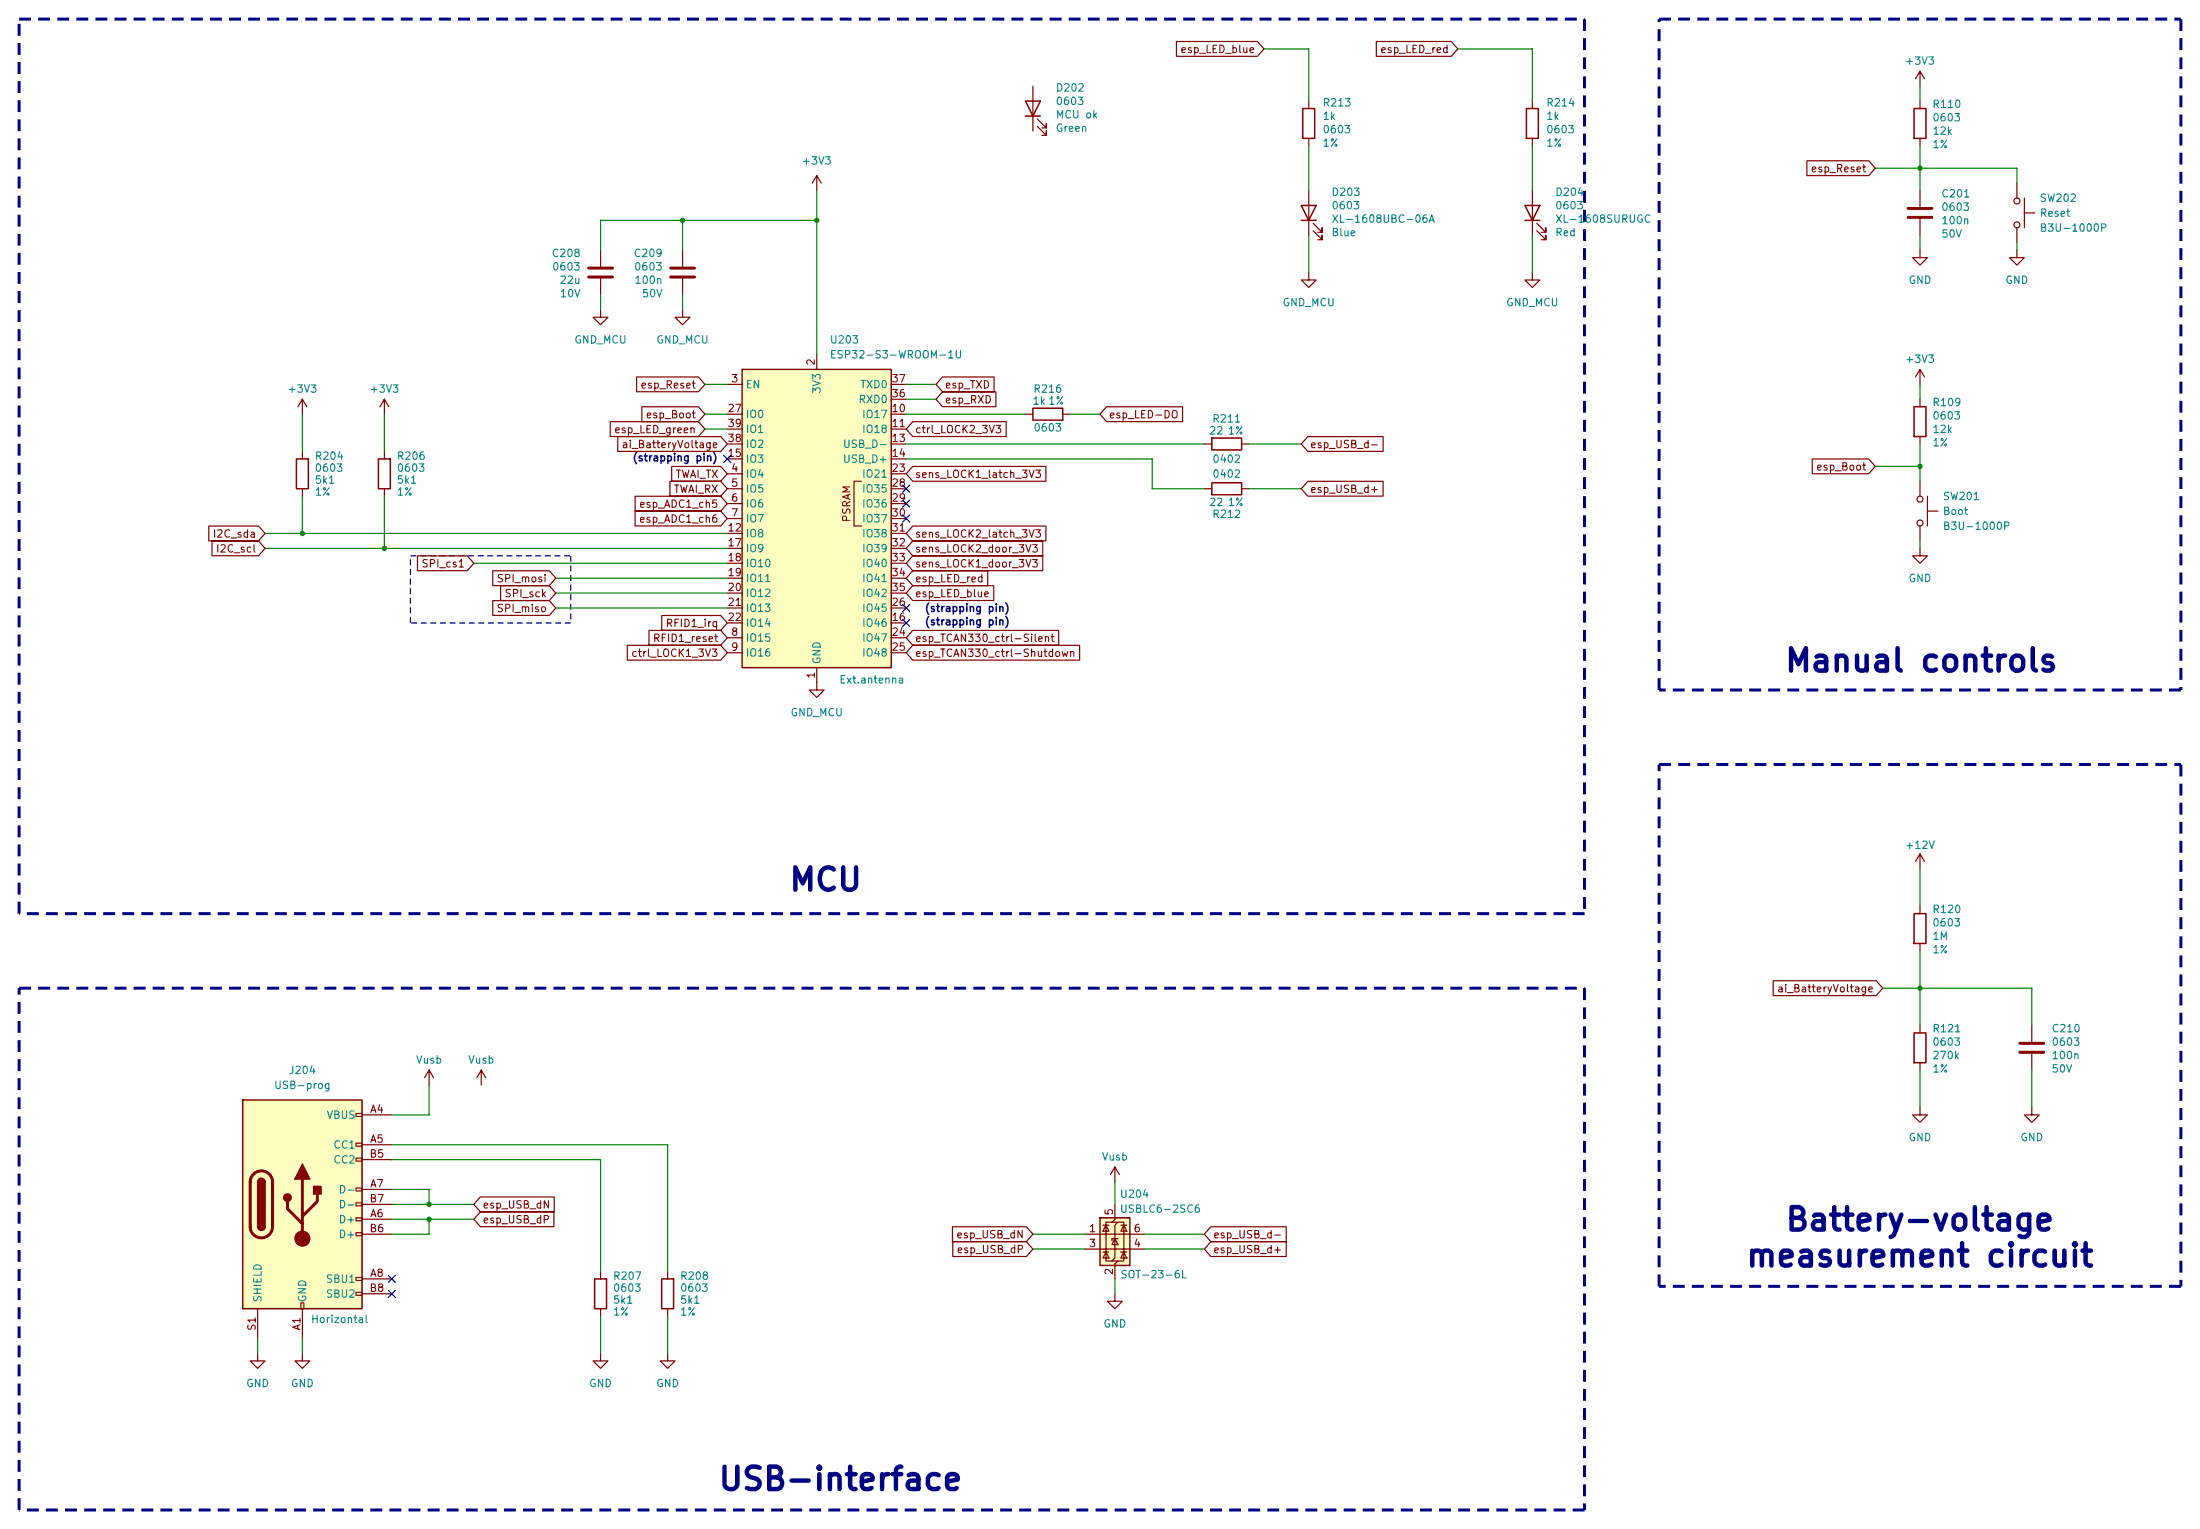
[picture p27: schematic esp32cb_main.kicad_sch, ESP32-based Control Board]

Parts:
C201, C209, C210: 100n; C_0603_1608Metric; LCSC part C1591
C208: 22u; C_0805_2012Metric; LCSC C907991
D202: MCU ok; LED_0603_1608Metric; LCSC part C965804
D203: XL-1608UBC-06A; LED_0603_1608Metric; LCSC C7371904
D204: XL-1608SURUGC; LED_0603_1608Metric; LCSC C5349934
J204: USB-prog; C3151749_USB_TYPE-C_Vertical
R109, R110: 12k; R_0603_1608Metric; LCSC C114659
R120: 1M; R_0603_1608Metric; LCSC C22935
R121: 270k; R_0603_1608Metric; LCSC C22965
R204, R206, R207, R208: 5k1; R_0603_1608Metric; LCSC part C2907044
R211, R212: 22; R_0402_1005Metric; LCSC part C114765
R213, R214, R216: 1k; R_0603_1608Metric; LCSC part C21190
SW201: Boot; SW_SPST_B3U-1000P; LCSC part C231329
SW202: Reset; SW_SPST_B3U-1000P; LCSC part C231329
U203: ESP32-S3-WROOM-1U; LCSC C3013946
U204: USBLC6-2SC6; SOT-23-6; LCSC part C7519

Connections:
+3V3: C208.2, C209.2, R109.1, R110.1, R204.2, R206.2, U203.2 (3V3); also elsewhere on the board
+12V: R120.1; also elsewhere on the board
GND: C201.1, C210.1, J204.A1 (GND), J204.A12 (GND), J204.B1 (GND), J204.B12 (GND), J204.S1 (SHIELD), R121.2, R207.1, R208.1, SW201.2, SW202.2, U204.2 (GND); also elsewhere on the board
GND_MCU: C208.1, C209.1, D203.1 (K), D204.1 (K), U203.1 (GND), U203.40 (GND), U203.41 (GND); also elsewhere on the board
I2C_scl: R206.1, U203.17 (IO9); also elsewhere on the board
I2C_sda: R204.1, U203.12 (IO8); also elsewhere on the board
unnamed: D203.2 (A), R213.2
unnamed: D204.2 (A), R214.2
unnamed: J204.A5 (CC1), R208.2
unnamed: J204.B5 (CC2), R207.2
unnamed: R216.1, U203.10 (IO17)
unnamed: R212.2, U203.14 (USB_D+)
unnamed: R211.2, U203.13 (USB_D-)
RFID1_irq: U203.22 (IO14); also elsewhere on the board
RFID1_reset: U203.8 (IO15); also elsewhere on the board
SPI_cs1: U203.18 (IO10); also elsewhere on the board
SPI_miso: U203.21 (IO13); also elsewhere on the board
SPI_mosi: U203.19 (IO11); also elsewhere on the board
SPI_sck: U203.20 (IO12); also elsewhere on the board
TWAI_RX: U203.5 (IO5); also elsewhere on the board
TWAI_TX: U203.4 (IO4); also elsewhere on the board
Vusb: J204.A4 (VBUS), J204.A9 (VBUS), J204.B4 (VBUS), J204.B9 (VBUS), U204.5 (VBUS); also elsewhere on the board
ai_BatteryVoltage: C210.2, R120.2, R121.1, U203.38 (IO2)
ctrl_LOCK1_3V3: U203.9 (IO16); also elsewhere on the board
ctrl_LOCK2_3V3: U203.11 (IO18); also elsewhere on the board
esp_ADC1_ch5: U203.6 (IO6); also elsewhere on the board
esp_ADC1_ch6: U203.7 (IO7); also elsewhere on the board
esp_Boot: R109.2, SW201.1, U203.27 (IO0)
esp_LED-DO: R216.2; also elsewhere on the board
esp_LED_blue: R213.1, U203.35 (IO42)
esp_LED_green: U203.39 (IO1)
esp_LED_red: R214.1, U203.34 (IO41)
esp_RXD: U203.36 (RXD0); also elsewhere on the board
esp_Reset: C201.2, R110.2, SW202.1, U203.3 (EN)
esp_TCAN330_ctrl-Shutdown: U203.25 (IO48); also elsewhere on the board
esp_TCAN330_ctrl-Silent: U203.24 (IO47); also elsewhere on the board
esp_TXD: U203.37 (TXD0); also elsewhere on the board
esp_USB_d+: R212.1, U204.4 (I/O2)
esp_USB_d-: R211.1, U204.6 (I/O1)
esp_USB_dN: J204.A7 (D-), J204.B7 (D-), U204.1 (I/O1)
esp_USB_dP: J204.A6 (D+), J204.B6 (D+), U204.3 (I/O2)
sens_LOCK1_door_3V3: U203.33 (IO40); also elsewhere on the board
sens_LOCK1_latch_3V3: U203.23 (IO21); also elsewhere on the board
sens_LOCK2_door_3V3: U203.32 (IO39); also elsewhere on the board
sens_LOCK2_latch_3V3: U203.31 (IO38); also elsewhere on the board

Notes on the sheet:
Battery-voltage measurement circuit
(strapping pin)
USB-interface
MCU
Manual controls

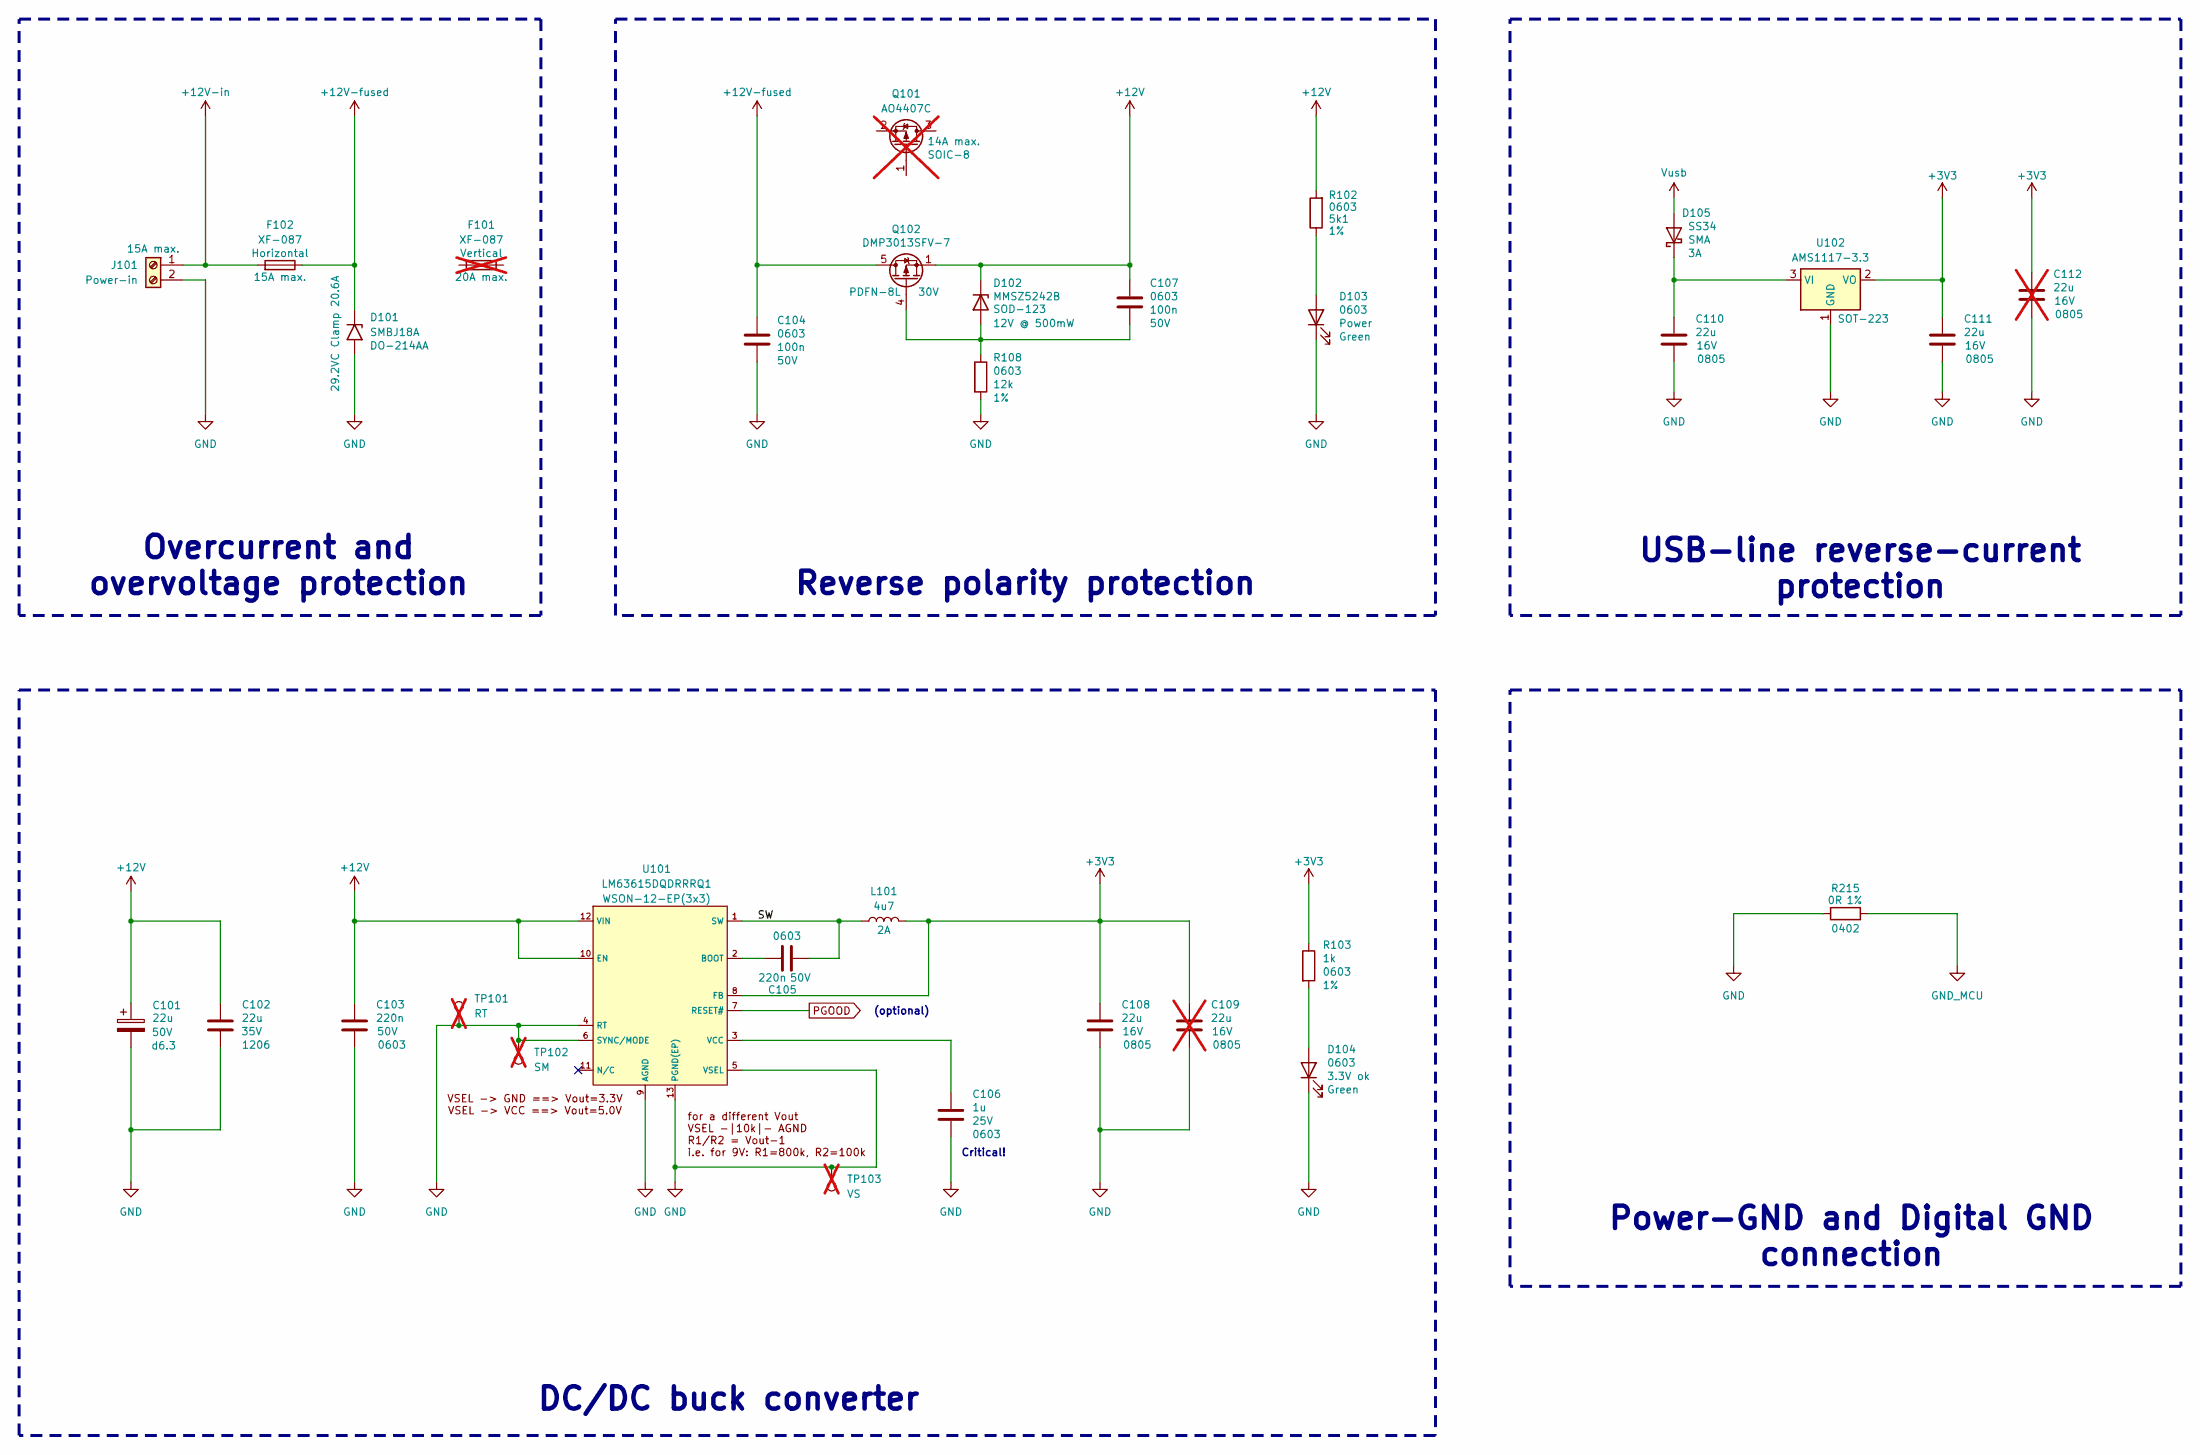
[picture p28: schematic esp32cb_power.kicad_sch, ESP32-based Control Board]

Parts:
C101: 22u; CP_Elec_6.3x5.7; LCSC part C2983377
C102: 22u; C_1206_3216Metric; LCSC part C342620
C103, C105: 220n; C_0603_1608Metric; LCSC part C64705
C104, C107: 100n; C_0603_1608Metric; LCSC part C1591
C106: 1u; C_0603_1608Metric; LCSC part C29936
C108, C110, C111: 22u; C_0805_2012Metric; LCSC part C98190
C109, C112: 22u; C_0805_2012Metric; LCSC part C98190; not fitted
D101: SMBJ18A; D_SMB; LCSC C151256
D102: MMSZ5242B; D_SOD-123; LCSC C82050
D103: Power; LED_0603_1608Metric; LCSC part C965804
D104: 3.3V ok; LED_0603_1608Metric; LCSC part C965804
D105: SS34; D_SMA; LCSC part C908680
F101: XF-087; FuseHolder_Blade_ATO_Littelfuse_FLR_178.6165; LCSC C41371864; not fitted
F102: XF-087; C206906_LittleFuse_01530007Z; LCSC C206906
J101: Power-in; AMASS_XT30PW-M_1x02_P2.50mm_Horizontal; LCSC C431092
L101: 4u7; L_Taiyo-Yuden_MD-4040; LCSC part C167828
Q101: AO4407C; SOIC-8_P-MOSFET; LCSC C469397; not fitted
Q102: DMP3013SFV-7; Diodes_PowerDI3333-8; LCSC C264098
R102: 5k1; R_0603_1608Metric; LCSC part C2907044
R103: 1k; R_0603_1608Metric; LCSC part C21190
R108: 12k; R_0603_1608Metric; LCSC C114659
R215: 0R; R_0402_1005Metric; LCSC C106231
TP101: RT; TestPoint_THTPad_D1.0mm_Drill0.5mm; not fitted
TP102: SM; TestPoint_THTPad_D1.0mm_Drill0.5mm; not fitted
TP103: VS; TestPoint_THTPad_D1.0mm_Drill0.5mm; not fitted
U101: LM63615DQDRRRQ1; WSON-12-1EP_3x3mm_P0.5mm_EP1.5x2.5mm; LCSC part C2873346
U102: AMS1117-3.3; SOT-223-3_TabPin2; LCSC C6186

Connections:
+3V3: C108.1, C109.1, C111.1, C112.1, L101.1, R103.1, U101.8 (FB), U102.2 (VO); also elsewhere on the board
+12V: C101.1, C102.1, C103.1, C107.2, D102.1 (K), Q102.1 (S), Q102.2 (S), Q102.3 (S), R102.2, U101.10 (EN), U101.12 (VIN); also elsewhere on the board
+12V-fused: C104.2, D101.1 (A1), F102.1, Q102.5 (D)
+12V-in: F102.2, J101.1
/Power/SW: C105.2, L101.2, U101.1 (SW)
GND: C101.2, C102.2, C103.2, C104.1, C106.2, C108.2, C109.2, C110.2, C111.2, C112.2, D101.2 (A2), D103.1 (K), D104.1 (K), J101.2, R108.2, R215.2, TP101.1 (1_1), TP102.1 (1_1), TP103.1 (1_1), U101.4 (RT), U101.5 (VSEL), U101.6 (SYNC/MODE), U101.9 (AGND), U101.13 (PGND(EP)), U102.1 (GND); also elsewhere on the board
GND_MCU: R215.1; also elsewhere on the board
unnamed: C107.1, D102.2 (A), Q102.4 (G), R108.1
unnamed: D103.2 (A), R102.1
unnamed: D104.2 (A), R103.2
unnamed: C110.1, D105.1 (K), U102.3 (VI)
unnamed: C105.1, U101.2 (BOOT)
unnamed: C106.1, U101.3 (VCC)
PGOOD: U101.7 (RESET#)
Vusb: D105.2 (A); also elsewhere on the board

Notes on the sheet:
Power-GND and Digital GND connection
(optional)
DC/DC buck converter
Critical!
Overcurrent and overvoltage protection
USB-line reverse-current protection
Reverse polarity protection

Board: 2 copper layers, 143 parts (0 on the bottom side), 98 nets, no tracks yet.

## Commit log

2026-07-03 60703 - hardware project started
    [esp32_control-board.kicad_pcb, esp32_control-board.kicad_sch, esp32cb_main.kicad_sch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]
2026-07-03 60703 - readme added
    [esp32_control-board.kicad_pcb, esp32_control-board.kicad_sch, esp32cb_main.kicad_sch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]
2026-07-07 60707 - schematics and readme updated, preliminary PCB-layout prepared
    [esp32_control-board.kicad_pcb, esp32_control-board.kicad_sch, esp32cb_inputs.kicad_sch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]
2026-07-07 60707 - schematics updated
    [esp32cb_main.kicad_sch]
2026-07-10 60710 - schematic and PCB-layout updated
    [esp32_control-board.kicad_pcb, esp32_control-board.kicad_sch, esp32cb_inputs.kicad_sch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]
2026-07-14 60714 - one of two I2C-mux ICs was removed, PCB-layout finished, start tracing
    [esp32_control-board.kicad_pcb, esp32_control-board.kicad_sch, esp32cb_inputs.kicad_sch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]
2026-07-14 60714 - traced 20%
    [esp32_control-board.kicad_pcb, esp32cb_main.kicad_sch]
2026-07-15 60714 - traced 25%
    [esp32_control-board.kicad_pcb, esp32cb_main.kicad_sch]
2026-07-15 60715 - traced 75%
    [esp32_control-board.kicad_pcb, esp32cb_main.kicad_sch]
2026-08-21 60821 - Schematic is under reconstruction for ver.2
    [esp32_control-board.kicad_sch, esp32cb_inputs.kicad_sch, esp32cb_locks.kicad_sch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]
2026-08-25 60825 - Schematic update and PCB-layout started
    [esp32_control-board.kicad_pcb, esp32_control-board.kicad_sch, esp32cb_can.kicad_sch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]
2026-08-28 60828 - Schematic updated, preliminary PCB-layout done
    [esp32_control-board.kicad_pcb, esp32_control-board.kicad_sch, esp32cb_can.kicad_sch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]
2026-09-05 60905 - fuse-holder replaced, led-strip connector added
    [esp32_control-board.kicad_pcb, esp32cb_locks.kicad_sch, esp32cb_main.kicad_sch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]
2026-09-08 60908 - PCB-layout updated
    [esp32_control-board.kicad_pcb, esp32cb_can.kicad_sch, esp32cb_main.kicad_sch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]
2026-09-11 60911 - PCB-layout updated
    [esp32_control-board.kicad_pcb, esp32cb_main.kicad_sch, esp32cb_power.kicad_sch]
2026-09-11 60911 - Schematic minor update
    [esp32cb_main.kicad_sch]
